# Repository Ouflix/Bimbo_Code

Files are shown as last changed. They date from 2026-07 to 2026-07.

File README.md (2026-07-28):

# Bimbo —> Robot Umanoid Asistiv pentru Kinetoterapie

Bimbo este un robot umanoid asistiv conceput pentru a ghida pacienți prin exerciții
de kinetoterapie: demonstrează mișcările fizic, ascultă și înțelege comenzi vocale
în limba română, oferă feedback în timp real și urmărește vizual pacientul pentru
a verifica dacă exercițiile sunt executate corect.

## De ce Bimbo
Kinetoterapia se bazează pe repetiție, precizie și motivație. Mulți pacienți efectuează exercițiile acasă fără îndrumare permanentă, ceea ce poate conduce la execuții incorecte și la o recuperare mai lentă.
BIMBO a fost creat pentru a reduce această problemă.
În loc să înlocuiască kinetoterapeutul, robotul acționează ca un asistent inteligent capabil să demonstreze exercițiile, să monitorizeze postura pacientului, să ofere corectări în timp real și să îl motiveze pe parcursul întregului proces de recuperare. Proiectul demonstrează modul în care robotica, viziunea artificială și tehnologiile moderne pot contribui la dezvoltarea unor soluții inovatoare pentru kinetoterapie, făcând recuperarea mai accesibilă, mai eficientă și mai atractivă.

## Ce face Bimbo

- **Ascultă în permanență** un cuvânt de trezire ("hey Bimbo") folosind un model
  local `openWakeWord`, fără a trimite audio în cloud până nu e nevoie.
- **Transcrie vorbirea în română** în timp real prin Google Cloud Speech-to-Text.
- **Conversează natural**, prin OpenAI, cu o personalitate dedicată de asistent de
  kinetoterapie: instrucțiuni scurte, ton încurajator, întreabă când îi lipsesc
  detalii (câte repetări, ce braț) și se oprește imediat dacă pacientul semnalează
  durere.
- **Vede și analizează pacientul**: verifică cu MediaPipe Pose dacă mișcarea (ex.
  ridicarea umerilor sau a coatelor) este executată corect, și poate urmări o
  persoană cu YOLOv8 pentru a se deplasa spre ea.
- **Execută mișcări fizice reale**: brațele sunt controlate prin servomotoare
  (PCA9685 + MG996R) cu rutine predefinite (flexie umăr, abducție, flexie cot,
  rotație antebraț, salut), iar baza mobilă e acționată de motoare DC comandate
  printr-un ESP32 conectat prin serial.
- **Vorbește** răspunsurile generate, folosind ElevenLabs pentru sinteza vocală.
- **Are o față expresivă**: un display TFT care randează un ochi animat (clipește,
  își mișcă privirea) pentru a da robotului un aspect mai viu.

## Arhitectură software

```
main.py                  → punctul de intrare: wake word → STT → AI → acțiune/TTS
modules/                 → toată logica robotului
  ai_request.py          → conversația cu OpenAI + apelurile de funcții (tool calls)
                           + trunchiere automată a istoricului conversației
  STT.py                 → transcriere vocală RO (Google Cloud Speech)
  microphone.py          → variantă de transcriere EN (Vosk, offline)
  audio.py               → sinteză vocală (ElevenLabs)
  camera.py, base64encoding.py → captură + encodare imagini pentru viziune
  pose_detection.py      → verificare corectitudine exerciții (MediaPipe)
  movement_sequence.py   → urmărire persoană cu YOLOv8 + navigație
  arm_controller.py      → mișcările brațelor (servo, PCA9685) + mecanism de
                           siguranță (stop_event) pentru întreruperea imediată
                           a mișcării în caz de durere semnalată
  motor.py, motor_hc595.py, ultrasonicsensor.py → baza mobilă + senzori distanță
  motor_run.py           → legătura serială cu ESP32-ul care controlează motoarele
                           (rezistă gracios dacă ESP32 nu e conectat la pornire)
  display.py             → animația ochiului pe display-ul TFT
scripts/                 → scripturi separate de test/calibrare, rulate manual
  arm_controller_test.py → meniu interactiv pentru testarea fiecărei mișcări
  calibrate_right.py     → calibrare unghiuri servo braț drept
  face_analysis.py       → analiză emoție facială (DeepFace), experimental
  openWakeWordBimbo.py   → test izolat pentru wake word, fără restul pipeline-ului
config/                  → functions.json (tool-urile expuse către OpenAI) + template credențiale
models/                  → yolov8n.pt (model YOLO pentru detecție/urmărire persoane)
assets/                  → sunete, imagini pentru display, poze temporare capturate
docs/                    → roadmap și note de dezvoltare
```

## Hardware

- Raspberry Pi 5 —> orchestrare software (wake word, AI, viziune)
- ESP32 —> control motoare în timp real, comunicare serială cu RPi5
- Convertoare Pololu (D24V50F5 si D24V150F6)
- 8 x Servomotoare MG996V pilotate prin placa PCA9685 (16 canale)
- Senzor hall de curent cu protectie la supracurent WCS1700
- Cameră RPi (Picamera2) pentru viziune și urmărire
- Display TFT (ST7735) pentru "fața" robotului
- Baterie custom 4S LiFePO4 + BMS
- Punți H BTS7960 pentru control complet asupra motoarelor DC
- 4 x Motoare DC
- Luxonis OAK-D Lite
- Microfon USB
- Boxă portabilă JBL
- (optional) Placa de protectie supratensiune eFuse conceputa in Kicad de catre noi
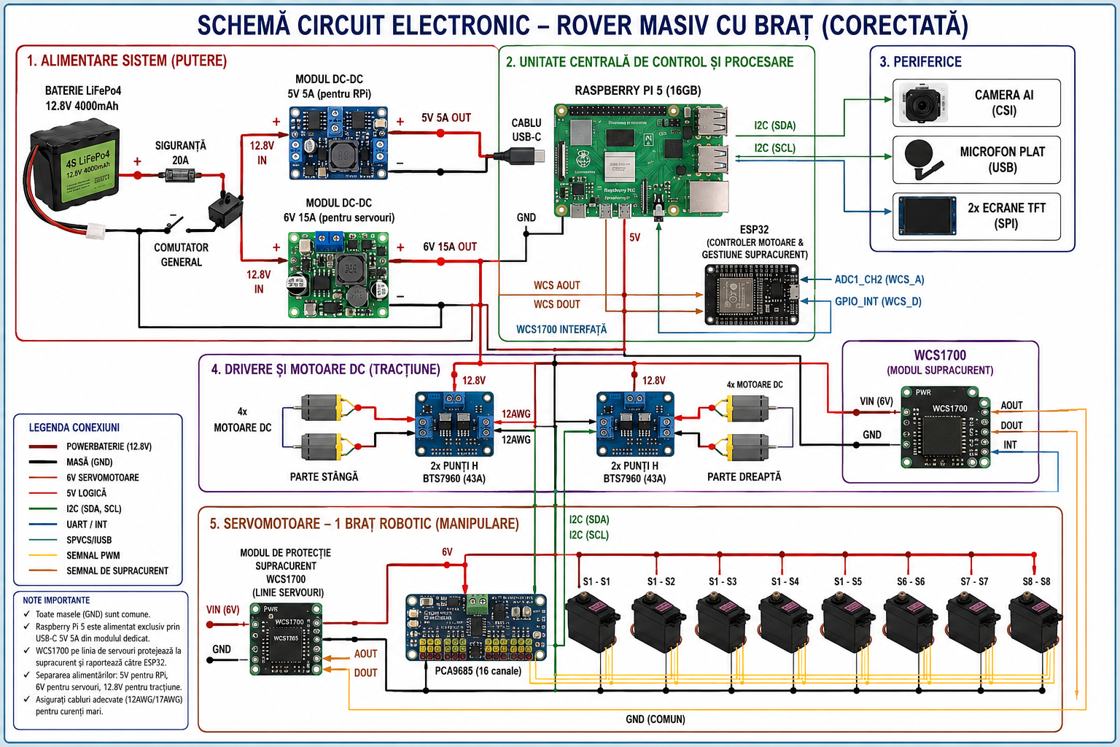
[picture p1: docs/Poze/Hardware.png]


## Instalare
1. Clonează repo-ul și instalează dependențele Python:

   ```bash
   git clone <link-ul-repo-ului-tau>
   cd Bimbo_Code
   pip install -r requirements.txt
   ```

   > Pe Raspberry Pi, `picamera2` se instalează de obicei prin `apt`, nu prin `pip`:
   > `sudo apt install -y python3-picamera2`

2. Copiază `.env.example` în `.env` și completează-ți propriile chei:

   ```bash
   cp .env.example .env
   ```

   Ai nevoie de:
   - o cheie **OpenAI** (`OPENAI_API_KEY`) — modelele de chat/viziune folosite sunt
     configurabile prin `OPENAI_CHAT_MODEL` / `OPENAI_VISION_MODEL`, cu valori
     implicite deja setate
   - o cheie **ElevenLabs** (`ELEVENLABS_API_KEY`)
   - un fișier de service account **Google Cloud** pentru Speech-to-Text — pune-l
     la `config/speech_to_text_credentials.json` (structura e în
     `config/speech_to_text_credentials.example.json`) sau indică alt path prin
     `GOOGLE_APPLICATION_CREDENTIALS`

3. Pune modelul de wake word (`hey_bimbo.onnx`) și fișierele audio (`beep.mp3`,
   `bimbo_speech_oncs.mp3`) în `assets/` (sau setează alte path-uri prin
   `WAKEWORD_MODEL_PATH`, `BEEP_SOUND_PATH`, `ROBOT_SPEECH_PATH` în `.env`).

4. Pornește robotul:

   ```bash
   python main.py
   ```

## Siguranță

Bimbo este gândit ca asistent, nu ca înlocuitor de personal medical: nu pune
diagnostice și confirmă mereu parametrii lipsă (repetări, braț) înainte să
execute o mișcare, pentru a evita acțiuni nedorite asupra pacientului.

Oprirea la semnale de durere funcționează pe **două niveluri independente**:

1. **Software** —> `arm_controller.py` expune un mecanism de tip stop-flag
   (`request_stop()` / `clear_stop()` / `is_stopped()`) verificat la fiecare pas
   al oricărei mișcări și între repetările fiecărui exercițiu. Când pacientul
   semnalează verbal durere, mișcarea curentă se întrerupe în cel mult un pas,
   nu la finalul întregii rutine, iar brațele revin în poziția de repaus (`home`).
2. **Hardware** —> un senzor de curent montat pe linia de alimentare a servourilor
   detectează stall-ul unui servo (curent anormal de mare, semn de blocaj mecanic)
   și taie alimentarea tuturor servourilor, independent de starea software-ului.
   Acest nivel funcționează chiar dacă AI-ul, STT-ul sau logica de mai sus
   dau fail dintr-un motiv neprevăzut. Totodata robotul este echipat cu un buton 
   ON/OFF ce inchide intregul robot in caz de urgenta

## Testare

Componentele critice de siguranță și robustețe au fost testate **izolat, cu
hardware-ul robotului**:

- Mecanismul de protecție la stall: senzorul de curent WCS1700 monitorizează consumul servourilor prin ESP32, care 
  taie fizic alimentarea printr-un releu când detectează un stall susținut (curent peste prag timp de 150ms,   
  ca să ignore vârfurile normale de accelerație). ESP32 semnalează Raspberry Pi-ului prin serial, care întrerupe
  imediat rutina de exerciții în mijlocul execuției, nu la final și eliberează servourile. 
  Alimentarea rămâne tăiată până la o comandă explicită de resetare, moment în care robotul revine în siguranță la poziția home
- Trunchierea memoriei conversației (`ai_request.py`): testat cu 30 de runde de
  conversație simulate — istoricul rămâne mereu limitat, mesajul de sistem
  (personalitatea) nu se pierde niciodată.
- Reziliența la deconectarea ESP32-ului (`motor_run.py`): testat cu conexiunea
  serială mockuită să eșueze — programul continuă să ruleze și ignoră comenzile
  de motor, în loc să se blocheze la pornire.
- Viziune și urmărire (pose_detection_v2.py, oakDLiteTest.py): verificarea corectitudinii exercițiilor și urmărirea pacientului rulează pe o cameră stereo 
  OAK-D Lite prin DepthAI, testate pe robot.
  Pentru verificarea exercițiilor, landmark-urile 2D de la MediaPipe Pose sunt combinate cu harta de adâncime stereo: fiecare articulație e reproiectată în coordonate 
  metrice 3D folosind intrinsecii camerei, iar unghiurile articulare se calculează în spațiu, nu în proiecție. Astfel măsurătoarea nu mai depinde de poziția pacientului față de cameră. 
  Peste asta rulează două verificări suplimentare — un validator de traiectorie (durată, netezime, monotonie) și un test de „liveness” bazat pe variația în adâncime — care resping repetările executate incorect sau tentativele de a păcăli sistemul cu o imagine statică.
  Pentru urmărirea persoanei, detecția YOLOv6-nano rulează direct pe VPU-ul camerei, iar rețeaua spațială returnează coordonatele 3D ale persoanei detectate. Robotul se orientează și se apropie proporțional cu distanța măsurată, oprindu-se la o distanță prestabilită
- Control brațe și bază mobilă (`arm_controller.py`, `motor_run.py`, `movement.cpp`): fiecare mișcare a fost testată
  fizic pe servomotoare și motoarele DC, cu calibrarea unghiurilor.

Fluxul complet integrat (microfon real → wake word → STT → AI → servo fizic)
a putut fi testat end-to-end datorita livarii componentei lipsa.

## Componente care nu sunt scrise/create integral de autor

Conform regulamentului InfoEducație (secțiunea roboți), se specifică explicit:

- `models/yolov8n.pt` —> model pretrained YOLOv8 (Ultralytics), nefolosit re-antrenat
  de autor, folosit ca atare pentru detecție/urmărire persoane.
- Framework-ul `openWakeWord` —> folosit ca bibliotecă pentru detecția cuvântului
  de trezire; modelul specific `hey_bimbo.onnx` a fost antrenat separat de autor
  pe acest framework.

## Servicii cloud externe (apelate prin API):

* OpenAI — creierul conversațional și de viziune.

* Google Cloud Speech-to-Text — transcriere vocală în română.

* ElevenLabs — sinteza vocală (TTS).

## Fiecare componenta mecanica a fost:
 	-proiectată în Onshape;
 	-optimizată pentru imprimare 3D;
## Materiale utilizate:
 	-PETG cu fibră de carbon;
 	-PLA;
Modelele 3D (fișiere .stl) se găsesc în docs/Proiectare/.

## Roadmap

Vezi [docs/ROADMAP.md](docs/ROADMAP.md) pentru direcțiile de dezvoltare viitoare.

## Context

Proiect realizat de catre Popa Victor (Programare si Hardware) si Radu Ghica (Design si Printare), ca parte a pregătirii pentru competiția
**InfoEducație**, cu scopul de a combina robotică, viziune computerizată și AI
conversațional într-un asistent fizic util pentru recuperare medicală.

## Surse și tehnologii utilizate
Limbaje: Python (aplicație principală), C++ (firmware ESP32)

* AI / ML: OpenAI (chat + vision + function calling), MediaPipe Pose, YOLOv8, openWakeWord, Vosk, DeepFace

* Voce: Google Cloud Speech-to-Text (STT), ElevenLabs (TTS)

* Control hardware: Adafruit CircuitPython (PCA9685 / ServoKit), gpiozero, pyserial

* Viziune: OpenCV, Picamera2, OAK-D Lite (Luxonis)

* Proiectare: Onshape (mecanică), KiCad (placă eFuse)

## Poze
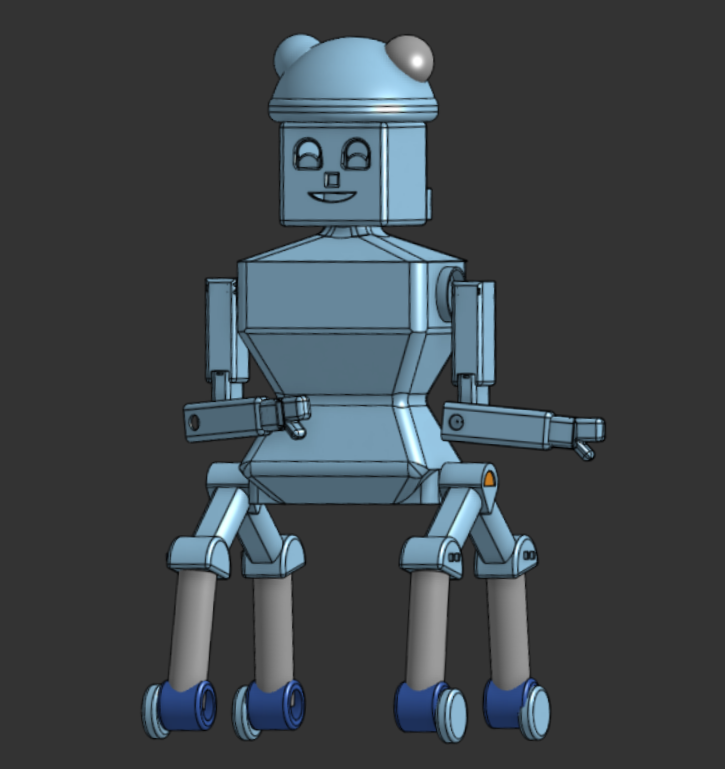
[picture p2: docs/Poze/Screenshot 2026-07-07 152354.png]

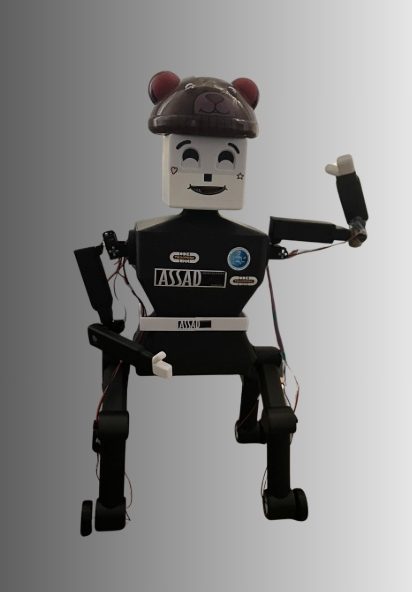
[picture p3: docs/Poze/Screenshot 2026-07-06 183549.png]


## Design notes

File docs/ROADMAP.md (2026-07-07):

# Roadmap

Lucruri planificate pentru versiunile următoare ale proiectului:

- [ ] Manipulare liberă a motoarelor (control mai fin, fără pattern-uri predefinite)
- [ ] Îmbunătățirea personalității AI-ului și a capacității acestuia de a decide
      mai bine când trebuie și când nu trebuie să apeleze o funcție (tool call)
- [ ] Adaugarea navigatiei autonome folosing camera de adancime OakD Lite FF
- [ ] Integrarea eFuse-ului dezvoltat de noi in KiCad atunci cand acesta va sosi de la JLCPCB

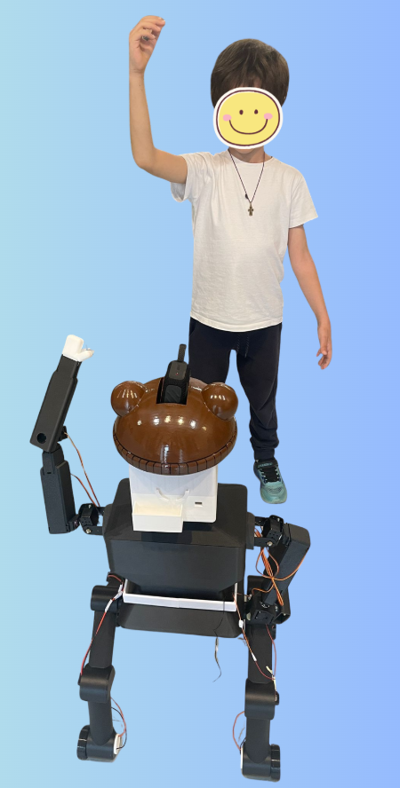
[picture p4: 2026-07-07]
docs/Poze/Screenshot 2026-07-06 185237.png

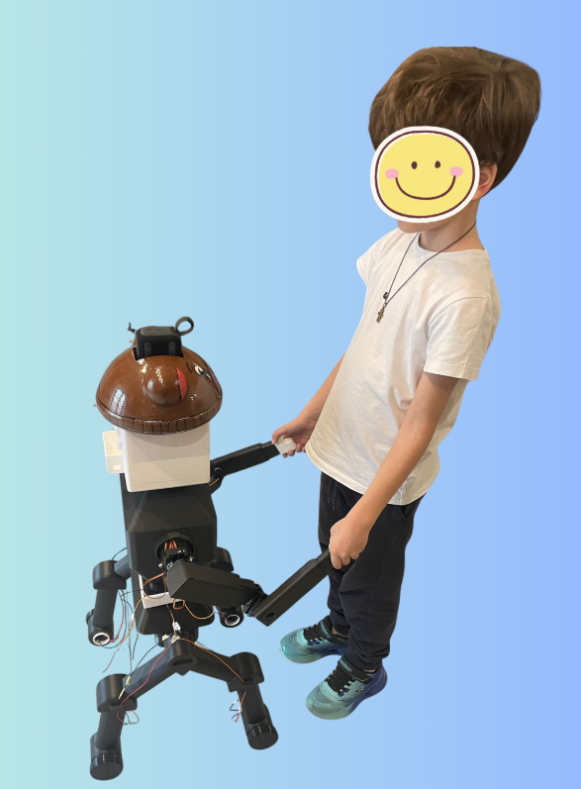
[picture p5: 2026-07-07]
docs/Poze/Screenshot 2026-07-06 185138.png

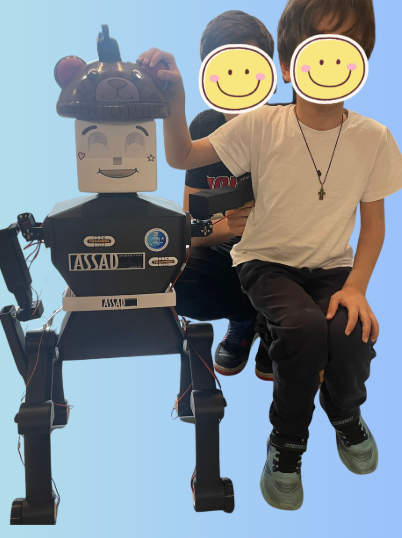
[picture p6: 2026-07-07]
docs/Poze/Screenshot 2026-07-06 185506.png

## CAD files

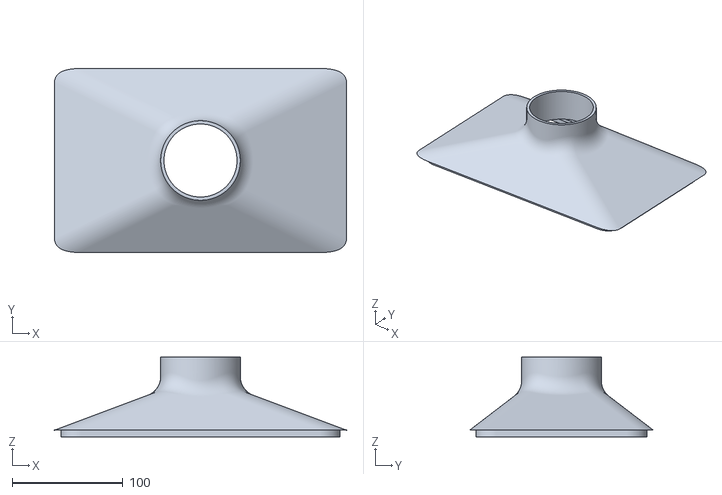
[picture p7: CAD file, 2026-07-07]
docs/Proiectare/umerus (1).stl
264.0 x 166.2 x 72.0

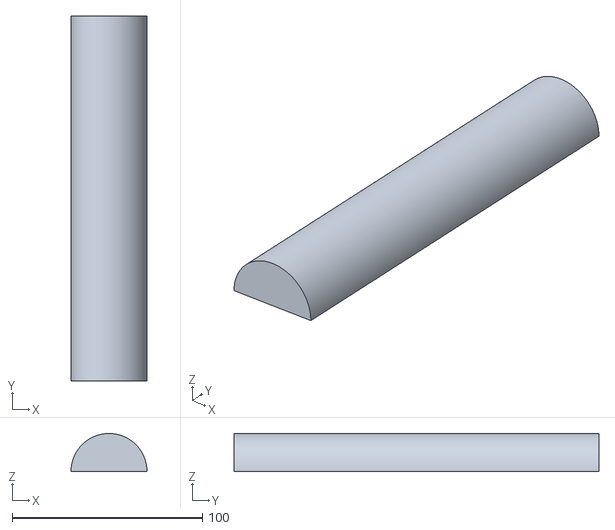
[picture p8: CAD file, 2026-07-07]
docs/Proiectare/PELVIUS OUT (1).stl
40.0 x 192.0 x 20.0

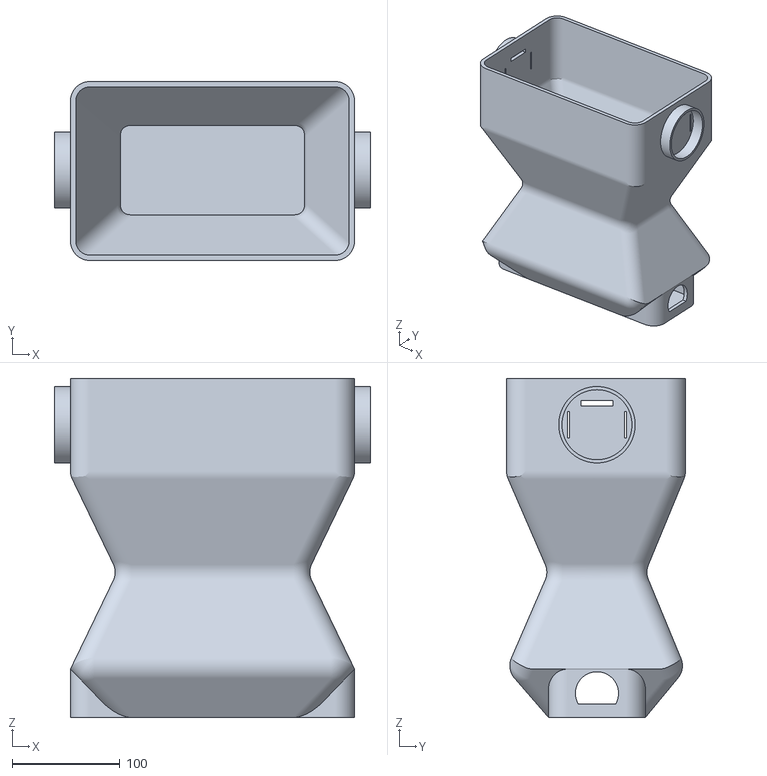
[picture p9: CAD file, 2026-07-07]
docs/Proiectare/trunchius (1).stl
294.0 x 166.2 x 315.0

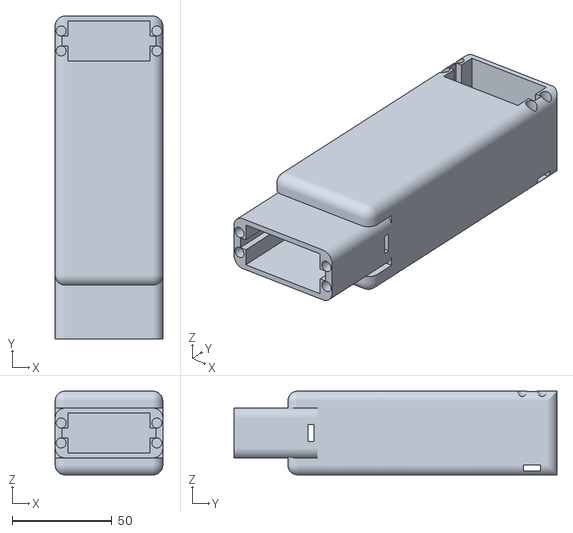
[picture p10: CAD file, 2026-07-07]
docs/Proiectare/bratus real.stl
54.0 x 162.0 x 42.0

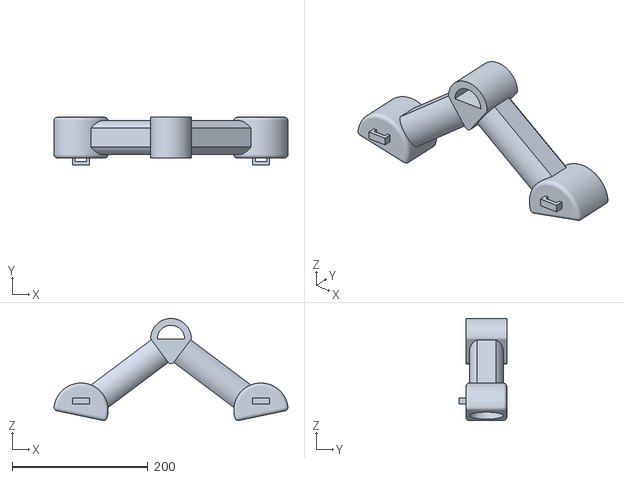
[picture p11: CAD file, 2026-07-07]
docs/Proiectare/gambus.stl
344.5 x 70.0 x 150.3

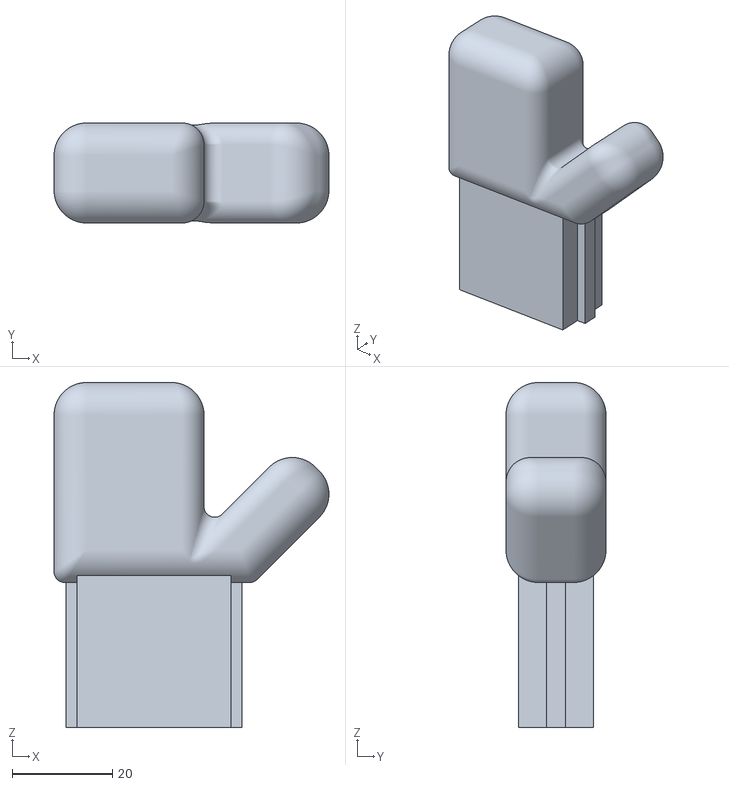
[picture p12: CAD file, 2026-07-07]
docs/Proiectare/manus (1).stl
55.0 x 20.0 x 69.0

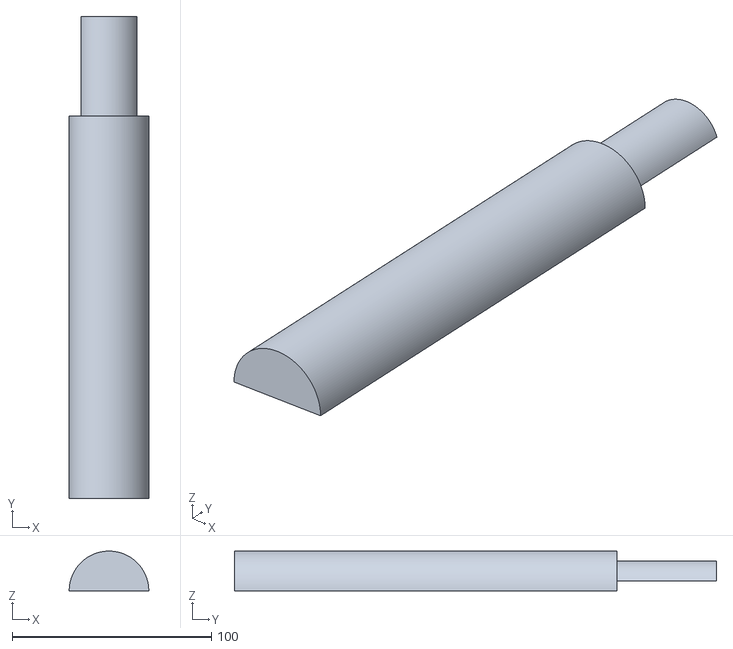
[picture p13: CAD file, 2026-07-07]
docs/Proiectare/PELVIUS IN (1).stl
40.0 x 242.0 x 20.0

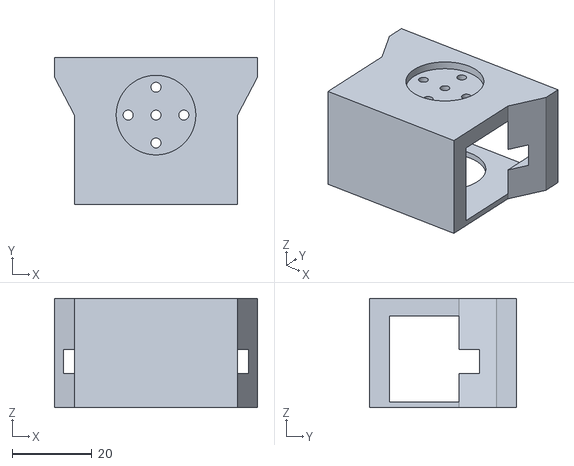
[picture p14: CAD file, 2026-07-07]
docs/Proiectare/cotus (1).stl
51.0 x 37.0 x 27.5

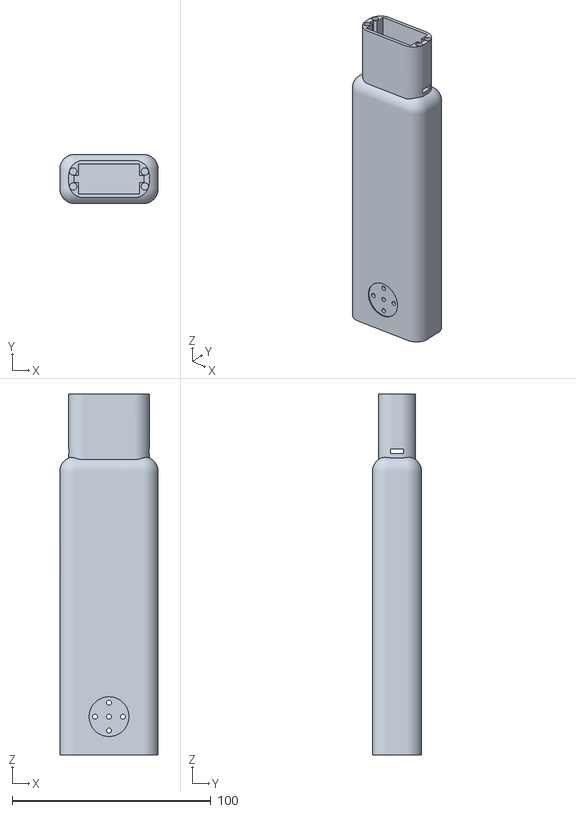
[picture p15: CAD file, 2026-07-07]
docs/Proiectare/bratus micus suportus (1).stl
49.5 x 24.8 x 181.5

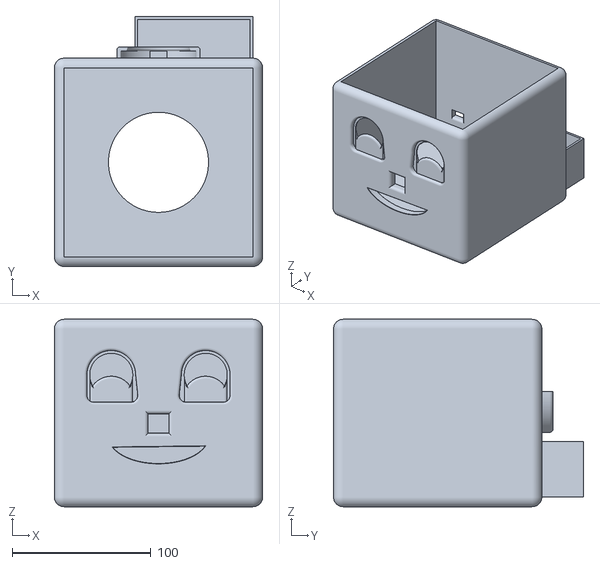
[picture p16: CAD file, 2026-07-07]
docs/Proiectare/capusorus (1).stl
150.0 x 180.0 x 135.0

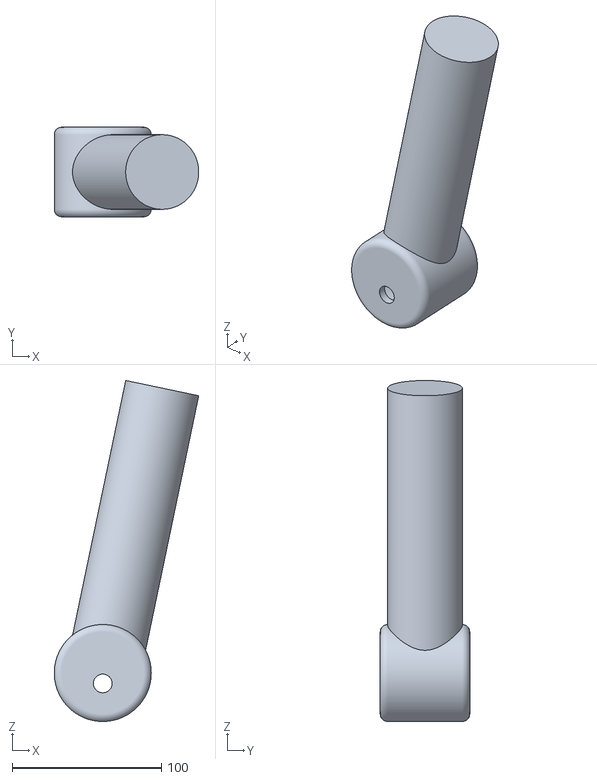
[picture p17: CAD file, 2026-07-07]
docs/Proiectare/coapsus.stl
96.8 x 60.0 x 228.5

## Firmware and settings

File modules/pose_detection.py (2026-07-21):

'''
Aceasta este versiunea 2.0 a scriptului de detectie a pozitiei corpului (folosit pentru validarea exercitiilor executate de catre pacient). Initial folosisem o camera generica de raspberry pi ,dar
la sosirea camerei Luxonis Oak D Lite am lucrat la implementarea acestei versiuni ce se foloseste de DepthAi V3. Codul a fost facut integral de catre mine fiind testat pe doua exercitii (flexie umar si 
abductie umar)
'''

import time
import depthai as dai
import cv2
import numpy as np
import mediapipe as mp
from collections import deque


def _angle_3d(a, b, c):
    if a is None or b is None or c is None:
        return None
    ba = a - b
    bc = c - b
    nba = np.linalg.norm(ba)
    nbc = np.linalg.norm(bc)
    if nba < 1e-6 or nbc < 1e-6:
        return None
    cosv = np.dot(ba, bc) / (nba * nbc)
    cosv = np.clip(cosv, -1.0, 1.0)
    return float(np.degrees(np.arccos(cosv)))


def _deproject(u, v, z, fx, fy, cx, cy):
    x = (u - cx) * z / fx
    y = (v - cy) * z / fy
    return np.array([x, y, z], dtype=np.float32)


def _sample_depth(depth_frame, u, v, win=4):
    h, w = depth_frame.shape
    u0, u1 = max(0, u - win), min(w, u + win + 1)
    v0, v1 = max(0, v - win), min(h, v + win + 1)
    patch = depth_frame[v0:v1, u0:u1]
    valid = patch[patch > 0]
    if valid.size == 0:
        return None
    return float(np.median(valid)) / 1000.0


class TrajectoryValidator:
    def __init__(self, neutral_range, target_range, increasing,
                 min_frames=5, max_frames=240, max_jump=45, monotonic_ratio=0.5):
        self.neutral_range = neutral_range
        self.target_range = target_range
        self.increasing = increasing
        self.min_frames = min_frames
        self.max_frames = max_frames
        self.max_jump = max_jump
        self.monotonic_ratio = monotonic_ratio
        self.reset()

    def reset(self):
        self.state = "WAIT_NEUTRAL"
        self.history = deque(maxlen=300)
        self.frames_in_motion = 0

    def _in(self, angle, rng):
        return rng[0] <= angle <= rng[1]

    def _smooth_and_monotonic(self):
        if len(self.history) < 3:
            return True
        diffs = np.diff(list(self.history))
        if np.max(np.abs(diffs)) > self.max_jump:
            return False
        good = np.sum(diffs > 0) if self.increasing else np.sum(diffs < 0)
        return good / len(diffs) >= self.monotonic_ratio

    def update(self, angle):
        if angle is None:
            return "TRACKING_LOST"

        if self.state == "WAIT_NEUTRAL":
            if self._in(angle, self.neutral_range):
                self.state = "READY"
            return "WAIT_NEUTRAL"

        if self.state == "READY":
            if not self._in(angle, self.neutral_range):
                self.state = "IN_MOTION"
                self.frames_in_motion = 0
                self.history.clear()
                self.history.append(angle)
            return "READY"

        if self.state == "IN_MOTION":
            self.frames_in_motion += 1
            self.history.append(angle)

            if self.frames_in_motion > self.max_frames:
                self.reset()
                return "TOO_SLOW"

            if self._in(angle, self.target_range):
                if self.frames_in_motion < self.min_frames:
                    self.reset()
                    return "TOO_FAST"
                if not self._smooth_and_monotonic():
                    self.reset()
                    return "NOT_SMOOTH"
                self.state = "DONE"
                return "VALID_REP"
            return "IN_MOTION"

        return "DONE"

    def progress(self, angle):
        if angle is None:
            return 0.0
        n_mid = sum(self.neutral_range) / 2
        t_mid = sum(self.target_range) / 2
        if t_mid == n_mid:
            return 0.0
        p = (angle - n_mid) / (t_mid - n_mid)
        return float(np.clip(p, 0.0, 1.0))


class LivenessChecker:
    def __init__(self, window=30, min_live_joints=2,
                 var_min=1e-8, var_max=0.5, min_depth_spread=0.02):
        self.window = window
        self.min_live_joints = min_live_joints
        self.var_min = var_min
        self.var_max = var_max
        self.min_depth_spread = min_depth_spread
        self.z_hist = {}

    def push(self, joint_idx, z):
        if z is None:
            return
        if joint_idx not in self.z_hist:
            self.z_hist[joint_idx] = deque(maxlen=self.window)
        self.z_hist[joint_idx].append(z)

    def check(self, current_pts):
        live_joints = 0
        for zs in self.z_hist.values():
            if len(zs) < self.window // 2:
                continue
            var = float(np.var(list(zs)))
            if self.var_min < var < self.var_max:
                live_joints += 1

        zs_now = [p[2] for p in current_pts.values() if p is not None]
        spread_ok = False
        if len(zs_now) >= 4:
            spread_ok = (max(zs_now) - min(zs_now)) > self.min_depth_spread

        temporal_ok = live_joints >= self.min_live_joints
        return temporal_ok and spread_ok, live_joints


def _build_pipeline(device, w=640, h=480, fps=20):
    pipeline = dai.Pipeline(device)

    cam_rgb = pipeline.create(dai.node.Camera).build(dai.CameraBoardSocket.CAM_A)
    mono_l = pipeline.create(dai.node.Camera).build(dai.CameraBoardSocket.CAM_B)
    mono_r = pipeline.create(dai.node.Camera).build(dai.CameraBoardSocket.CAM_C)

    rgb_out = cam_rgb.requestOutput(
        size=(w, h),
        type=dai.ImgFrame.Type.RGB888i,
        resizeMode=dai.ImgResizeMode.CROP,
        fps=fps,
    )
    mono_l_out = mono_l.requestOutput(size=(w, h), fps=fps)
    mono_r_out = mono_r.requestOutput(size=(w, h), fps=fps)

    stereo = pipeline.create(dai.node.StereoDepth)
    stereo.setDefaultProfilePreset(dai.node.StereoDepth.PresetMode.FAST_ACCURACY)
    stereo.setLeftRightCheck(True)
    stereo.setSubpixel(False)
    stereo.setExtendedDisparity(False)
    stereo.setDepthAlign(dai.CameraBoardSocket.CAM_A)
    stereo.setOutputSize(640, 480)
    mono_l_out.link(stereo.left)
    mono_r_out.link(stereo.right)

    sync = pipeline.create(dai.node.Sync)
    rgb_out.link(sync.inputs["rgb"])
    stereo.depth.link(sync.inputs["depth"])

    out_q = sync.out.createOutputQueue()
    return pipeline, out_q


EXERCISES = {
    0: {
        "name": "ARMS_HORIZONTAL_90",
        "success_msg": "Bravo! Ai ridicat corect bratele la orizontala",
        "shoulder_range": (60, 120),
        "elbow_range": (135, 181),
        "traj_joint": "shoulder",
        "traj_neutral": (0, 45),
        "traj_target": (60, 120),
        "traj_increasing": True,
    },
    1: {
        "name": "CACTUS_POSE",
        "success_msg": "Felicitari! Ai flexat foarte bine coatele, tine-o tot asa!",
        "shoulder_range": (65, 125),
        "elbow_range": (55, 125),
        "traj_joint": "elbow",
        "traj_neutral": (130, 181),
        "traj_target": (55, 125),
        "traj_increasing": False,
    },
}


def _draw_banner(img, text, color):
    h, w = img.shape[:2]
    (tw, th), _ = cv2.getTextSize(text, cv2.FONT_HERSHEY_SIMPLEX, 1.4, 4)
    by0 = h // 2 - th - 30
    by1 = h // 2 + th + 30
    overlay = img.copy()
    cv2.rectangle(overlay, (0, by0), (w, by1), color, -1)
    cv2.addWeighted(overlay, 0.45, img, 0.55, 0, img)
    tx = (w - tw) // 2
    ty = h // 2 + th // 2
    cv2.putText(img, text, (tx, ty),
                cv2.FONT_HERSHEY_SIMPLEX, 1.4, (255, 255, 255), 4)


def pose_detect(index, strict=True):
    if index not in EXERCISES:
        raise ValueError(f"index necunoscut: {index}")
    cfg = EXERCISES[index]

    mp_pose = mp.solutions.pose
    mp_draw = mp.solutions.drawing_utils
    pose = mp_pose.Pose(min_detection_confidence=0.6, min_tracking_confidence=0.6)
    L = mp_pose.PoseLandmark

    stable_buffer = deque(maxlen=8)

    traj = TrajectoryValidator(
        neutral_range=cfg["traj_neutral"],
        target_range=cfg["traj_target"],
        increasing=cfg["traj_increasing"],
    )
    liveness = LivenessChecker()

    BANNER_SEC = 1.2
    banner_text = None
    banner_color = (0, 0, 0)
    banner_until = 0.0

    REJECT_MSG = {
        "TOO_FAST": "Incearca din nou - mai lent",
        "TOO_SLOW": "Incearca din nou",
        "NOT_SMOOTH": "Incearca din nou - miscare lina",
        "NOT_LIVE": "Incearca din nou",
    }

    wanted = [L.LEFT_SHOULDER, L.RIGHT_SHOULDER, L.LEFT_ELBOW, L.RIGHT_ELBOW,
              L.LEFT_WRIST, L.RIGHT_WRIST, L.LEFT_HIP, L.RIGHT_HIP]

    target_hold_frames = 0
    HOLD_NEEDED = 15
    traj_done = False

    def pose_state(pts):
        if any(pts.get(i.value) is None for i in wanted):
            return "LOW_VISIBILITY", None, None

        l_sh = _angle_3d(pts[L.LEFT_HIP.value],  pts[L.LEFT_SHOULDER.value],  pts[L.LEFT_ELBOW.value])
        r_sh = _angle_3d(pts[L.RIGHT_HIP.value], pts[L.RIGHT_SHOULDER.value], pts[L.RIGHT_ELBOW.value])
        l_el = _angle_3d(pts[L.LEFT_SHOULDER.value],  pts[L.LEFT_ELBOW.value],  pts[L.LEFT_WRIST.value])
        r_el = _angle_3d(pts[L.RIGHT_SHOULDER.value], pts[L.RIGHT_ELBOW.value], pts[L.RIGHT_WRIST.value])

        if None in (l_sh, r_sh, l_el, r_el):
            return "LOW_VISIBILITY", None, None

        sr, er = cfg["shoulder_range"], cfg["elbow_range"]
        in_target = (sr[0] < l_sh < sr[1] and sr[0] < r_sh < sr[1] and
                     er[0] < l_el < er[1] and er[0] < r_el < er[1])

        if cfg["traj_joint"] == "shoulder":
            traj_ang = (l_sh + r_sh) / 2.0
        else:
            traj_ang = (l_el + r_el) / 2.0

        return ("IN_TARGET" if in_target else "NEUTRAL"), traj_ang, (l_sh, l_el)

    with dai.Device() as device:
        print(device.getUsbSpeed())
        pipeline, out_q = _build_pipeline(device)

        calib = device.readCalibration()
        K = np.array(calib.getCameraIntrinsics(dai.CameraBoardSocket.CAM_A, 640, 480))
        fx, fy = K[0, 0], K[1, 1]
        cx, cy = K[0, 2], K[1, 2]

        pipeline.start()
        try:
            while pipeline.isRunning():
                msg = out_q.get()
                in_rgb = msg["rgb"]
                in_depth = msg["depth"]
                frame = in_rgb.getCvFrame()
                depth = in_depth.getFrame()

                results = pose.process(frame)
                bgr = cv2.cvtColor(frame, cv2.COLOR_RGB2BGR)
                h, w = depth.shape

                overlay_lines = []

                if results.pose_landmarks:
                    mp_draw.draw_landmarks(bgr, results.pose_landmarks, mp_pose.POSE_CONNECTIONS)
                    lm = results.pose_landmarks.landmark

                    pts = {}
                    for idx in wanted:
                        p = lm[idx.value]
                        if p.visibility < 0.5:
                            pts[idx.value] = None
                            continue
                        u = int(round(p.x * w))
                        v = int(round(p.y * h))
                        if not (0 <= u < w and 0 <= v < h):
                            pts[idx.value] = None
                            continue
                        z = _sample_depth(depth, u, v)
                        pts[idx.value] = _deproject(u, v, z, fx, fy, cx, cy) if z else None
                        liveness.push(idx.value, z)

                    state, traj_ang, dbg = pose_state(pts)
                    stable_buffer.append(state)
                    stable_state = max(set(stable_buffer), key=stable_buffer.count)

                    traj_result = traj.update(traj_ang)
                    live_ok, live_joints = liveness.check(pts)

                    success = False
                    if strict:
                        if traj_result == "VALID_REP":
                            traj_done = True
                        success = (traj_done and
                                   stable_state == "IN_TARGET" and live_ok)
                    else:
                        if stable_state == "IN_TARGET":
                            target_hold_frames += 1
                        else:
                            target_hold_frames = 0
                        success = target_hold_frames >= HOLD_NEEDED

                    if success:
                        print(f"{cfg['name']} DETECTED"
                              f"{' (strict)' if strict else ' (mod usor)'}")
                        print(f"[TTS] {cfg['success_msg']}")
                        _draw_banner(bgr, "BINE EXECUTAT", (0, 150, 0))
                        cv2.imshow('Pose Detection 3D', bgr)
                        cv2.waitKey(int(BANNER_SEC * 1000))
                        break

                    if strict and traj_result == "VALID_REP" and not live_ok:
                        print("[ANTI-CHEAT] repetare respinsa: NOT_LIVE")
                        banner_text = REJECT_MSG["NOT_LIVE"]
                        banner_color = (0, 90, 200)
                        banner_until = time.time() + BANNER_SEC
                    elif strict and traj_result in ("TOO_FAST", "TOO_SLOW", "NOT_SMOOTH"):
                        print(f"[ANTI-CHEAT] repetare respinsa: {traj_result}")
                        banner_text = REJECT_MSG.get(traj_result, "Incearca din nou")
                        banner_color = (0, 90, 200)
                        banner_until = time.time() + BANNER_SEC

                    col_state = (0, 255, 0) if stable_state == "IN_TARGET" else (255, 255, 255)
                    overlay_lines.append((stable_state, col_state))
                    if traj_ang is not None:
                        overlay_lines.append((f"traj: {traj_result}  ({cfg['traj_joint']}={traj_ang:.0f})",
                                              (255, 255, 0)))
                    overlay_lines.append((f"live_joints: {live_joints}  live_ok: {live_ok}  done: {traj_done}",
                                          (255, 200, 0)))
                    if dbg is not None:
                        overlay_lines.append((f"Shoulder3D: {dbg[0]:.0f}  Elbow3D: {dbg[1]:.0f}",
                                              (200, 200, 0)))

                    prog = traj.progress(traj_ang)
                    bx, by, bw, bh = 10, 170, 300, 22
                    cv2.rectangle(bgr, (bx, by), (bx + bw, by + bh), (80, 80, 80), 1)
                    cv2.rectangle(bgr, (bx, by), (bx + int(bw * prog), by + bh),
                                  (0, 200, 0), -1)
                else:
                    overlay_lines.append(("NO PERSON", (0, 0, 255)))

                y = 40
                for text, col in overlay_lines:
                    scale = 1.0 if y == 40 else 0.6
                    thick = 3 if y == 40 else 2
                    cv2.putText(bgr, text, (10, y),
                                cv2.FONT_HERSHEY_SIMPLEX, scale, col, thick)
                    y += 32

                if banner_text is not None and time.time() < banner_until:
                    _draw_banner(bgr, banner_text, banner_color)
                elif time.time() >= banner_until:
                    banner_text = None

                cv2.imshow('Pose Detection 3D', bgr)
                if cv2.waitKey(1) & 0xFF == ord('q'):
                    break
        finally:
            pipeline.stop()
            pose.close()
            cv2.destroyAllWindows()


if __name__ == "__main__":
    pose_detect(0, False)

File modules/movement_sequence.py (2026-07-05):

import cv2
import numpy as np
from ultralytics import YOLO
from modules.motor_hc595 import turn, moveUntilStopped, shift_out, STOP, UNRESERVED
import time
import threading
from queue import Queue
import os
import subprocess
from modules.ultrasonicsensor import mesure_distance_low, mesure_distance_high
from enum import Enum
import signal
import sys

os.environ["OPENBLAS_NUM_THREADS"] = "1"
os.environ["MKL_NUM_THREADS"] = "1"

# Robot states
class RobotState(Enum):
    SEARCHING = "searching"
    TRACKING = "tracking"
    APPROACHING = "approaching"
    REACHED = "reached"
    STOPPED = "stopped"

# Constants
CONFIDENCE_THRESHOLD = 0.3  # Slightly higher for better detection accuracy
FOV_DEGREES = 62
TURN_SPEED = 0.5  # Reduced for more precise turning
TOLERANCE_PIXELS = 30  # Pixel tolerance for centering
MIN_SAFE_DISTANCE = 30  # Minimum safe distance in cm
MAX_SEARCH_TIME = 60  # Maximum search time in seconds
SEARCH_TURN_DEGREES = 45  # Degrees to turn when searching
TURN_DURATION_PER_DEGREE = 0.02  # Calibrate this based on your robot

# Global model management
class ModelManager:
    _model = None
    
    @classmethod
    def get_model(cls):
        if cls._model is None:
            print("Loading YOLO model...")
            cls._model = YOLO("yolov8n.pt")
            print("YOLO model loaded successfully")
        return cls._model

# Improved camera manager
class CameraManager:
    _instance = None
    _camera = None
    _lock = threading.Lock()
    
    @classmethod
    def initialize(cls):
        with cls._lock:
            if cls._camera is not None:
                cls.cleanup()
            
            # Kill any existing camera processes
            subprocess.run(["pkill", "-f", "libcamera"], stderr=subprocess.DEVNULL)
            time.sleep(0.5)
            
            from picamera2 import Picamera2
            try:
                cls._camera = Picamera2()
                config = cls._camera.create_preview_configuration(
                    main={"format": "RGB888", "size": (640, 480)},
                    buffer_count=4,
                    controls={
                        "FrameDurationLimits": (33333, 33333),  # 30fps
                        "AwbEnable": True,
                        "AeEnable": True
                    }
                )
                cls._camera.configure(config)
                cls._camera.start()
                time.sleep(1.0)  # Camera warm-up
                print("Camera initialized successfully")
                return cls._camera
            except Exception as e:
                print(f"Failed to initialize camera: {e}")
                cls.cleanup()
                raise
    
    @classmethod
    def cleanup(cls):
        with cls._lock:
            if cls._camera is not None:
                try:
                    cls._camera.stop()
                    cls._camera.close()
                except:
                    pass
                cls._camera = None
            subprocess.run(["pkill", "-f", "libcamera"], stderr=subprocess.DEVNULL)

# Main movement sequence class
class MovementSequence:
    def __init__(self, target_object):
        self.target_object = target_object.lower()
        self.model = ModelManager.get_model()
        self.camera = None
        self.state = RobotState.SEARCHING
        self.running = False
        self.target_last_seen = None
        self.search_direction = 1  # 1 for right, -1 for left
        self.no_target_count = 0
        self.frame_queue = Queue(maxsize=2)
        self.stop_motors()
        
    def stop_motors(self):
        """Ensure motors are stopped"""
        try:
            shift_out(STOP, UNRESERVED)
            time.sleep(0.1)
        except Exception as e:
            print(f"Error stopping motors: {e}")
    
    def check_obstacles(self):
        """Check if path is clear"""
        try:
            dist_low = mesure_distance_low()
            dist_high = mesure_distance_high()
            print(f"Distance readings - Low: {dist_low}cm, High: {dist_high}cm")
            return dist_low > MIN_SAFE_DISTANCE and dist_high > MIN_SAFE_DISTANCE
        except Exception as e:
            print(f"Error reading sensors: {e}")
            return False
    
    def turn_robot(self, degrees):
        """Turn robot by specified degrees"""
        self.stop_motors()
        time.sleep(0.1)
        
        duration = abs(degrees) * TURN_DURATION_PER_DEGREE
        print(f"Turning {degrees} degrees for {duration:.2f} seconds")
        
        turn(degrees, duration)
        self.stop_motors()
        time.sleep(0.2)
    
    def move_forward(self):
        """Move forward safely"""
        if not self.check_obstacles():
            print("Obstacle detected, cannot move forward")
            return False
        
        self.stop_motors()
        time.sleep(0.1)
        
        print("Moving forward until obstacle detected")
        result = moveUntilStopped()
        
        self.stop_motors()
        time.sleep(0.2)
        
        return result
    
    def process_frame(self, frame):
        """Process a single frame for object detection"""
        # Resize for faster processing
        small_frame = cv2.resize(frame, (320, 240))
        
        # Run detection
        results = self.model(small_frame, conf=CONFIDENCE_THRESHOLD, verbose=False)[0]
        
        # Scale factors
        scale_x = frame.shape[1] / 320
        scale_y = frame.shape[0] / 240
        
        # Create display frame
        display_frame = frame.copy()
        
        # Add UI elements
        cv2.putText(display_frame, f"State: {self.state.value}", (10, 30), 
                   cv2.FONT_HERSHEY_SIMPLEX, 0.7, (0, 255, 0), 2)
        cv2.putText(display_frame, f"Target: {self.target_object}", (10, 60),
                   cv2.FONT_HERSHEY_SIMPLEX, 0.7, (0, 255, 0), 2)
        
        # Draw center line
        center_x = frame.shape[1] // 2
        cv2.line(display_frame, (center_x, 0), (center_x, frame.shape[0]), (255, 0, 0), 1)
        
        target_detected = False
        target_info = None
        
        # Process detections
        for box in results.boxes:
            cls = int(box.cls[0])
            name = self.model.names[cls].lower()
            confidence = float(box.conf[0])
            
            # Scale coordinates
            x1, y1, x2, y2 = map(int, box.xyxy[0])
            x1, x2 = int(x1 * scale_x), int(x2 * scale_x)
            y1, y2 = int(y1 * scale_y), int(y2 * scale_y)
            
            # Draw bounding box
            is_target = name == self.target_object
            color = (0, 255, 0) if is_target else (255, 0, 0)
            cv2.rectangle(display_frame, (x1, y1), (x2, y2), color, 2)
            cv2.putText(display_frame, f"{name} {confidence:.2f}", (x1, y1-10), 
                       cv2.FONT_HERSHEY_SIMPLEX, 0.5, color, 2)
            
            if is_target and confidence > CONFIDENCE_THRESHOLD:
                target_detected = True
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

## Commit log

2026-07-21 Add pose_detection_v2.py for improved detection
    Introduced version 2.0 of the pose detection script, which utilizes DepthAi V3 with the Luxonis Oak D Lite camera.
2026-07-22 Improve clarity of stall protection description
    Clarified the sentence structure regarding the stall protection mechanism.
